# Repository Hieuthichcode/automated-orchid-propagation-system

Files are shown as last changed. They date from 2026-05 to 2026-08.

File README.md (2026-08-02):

# Automated Orchid Propagation System

> A hybrid 2D–3D RGB-D method for estimating the
> growth axis of Phalaenopsis orchid buds and converting the estimated axis into
> a robot-referenced 6-DOF grasp pose, integrated with a custom 6-DOF robot arm.

---

## Demo

<p align="center">
  System Architecture<br/>
  <em>System architecture — Embedded vision computer + 6-DOF robot arm with RGB-D sensing</em>
</p>

<p align="center">
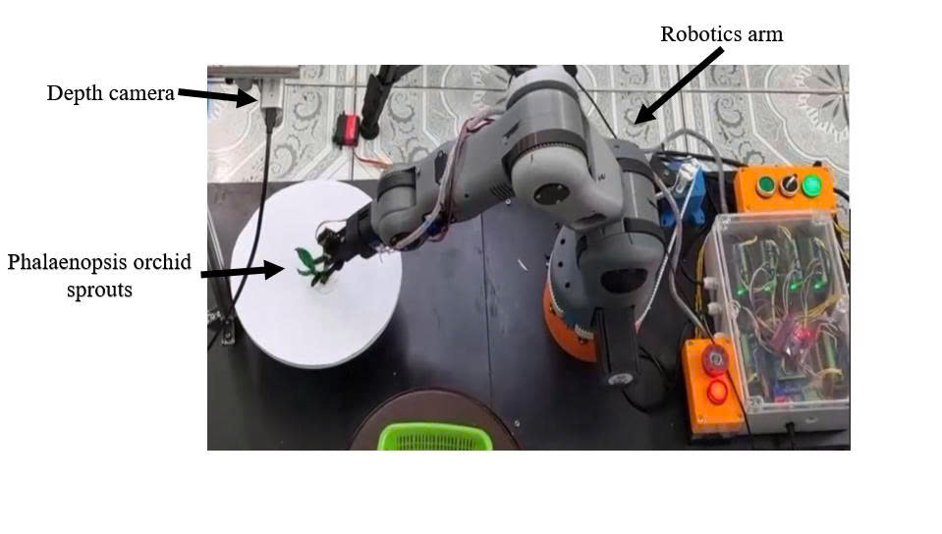
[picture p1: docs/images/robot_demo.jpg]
Robot Demo
  <br/>
  <em>Physical prototype — 6-DOF robot arm performing orchid shoot manipulation</em>
</p>

---

## Overview

This repository implements a hybrid 2D–3D RGB-D method for estimating the
growth axis of Phalaenopsis orchid buds and converting the estimated axis into
a robot-referenced 6-DOF grasp pose. The pipeline combines instance
segmentation, 2D skeleton guidance, depth-based point-cloud processing, and PCA
axis estimation.

This project combines a custom-built **6-DOF serial robot arm** with an **Intel RealSense D435 depth camera** and a **YOLOv8 instance segmentation model** to autonomously detect, locate, and manipulate orchid shoots (*mầm lan*) — replacing manual labor in orchid propagation.

### System Pipeline

```
RGB-D acquisition (RealSense D435)
        │
        ▼
Instance segmentation (YOLOv8, v8_seg_1024.pt)
        │  detect & segment each orchid bud
        ▼
2D skeleton extraction
        │  tip detection, cutting point & angle
        ▼
Point-cloud reconstruction and filtering
        │  depth-based 3D extraction, outlier removal
        ▼
Skeleton-guided branch selection
        │
        ▼
PCA growth-axis estimation
        │
        ▼
Camera-to-robot transformation
        │
        ▼
6-DOF grasp pose → Arduino Mega 2560 (IK on-board)
        │  quintic trajectory interpolation
        ▼
6-DOF Stepper Robot → Cut / Grip / Branch
```

---

## Data and pretrained models

Representative image samples, trained model weights, and the raw numerical
evaluation data are available in the
[Google Drive folder](https://drive.google.com/drive/folders/1FqTuIMWtxHYL037exPB-O3m-0CBoGs5N?usp=drive_link).

The shared folder contains:

- `Images/`: representative JPEG images;
- `Model_train/weights/best.pt`: recommended segmentation weight for inference;
- `Model_train/weights/epoch360.pt` and `last.pt`: additional checkpoints;
- `Data_test/angularError_data.xlsx`: angular-error evaluation data;
- `Data_test/Time_data.xlsx`: processing-time evaluation data.

The dataset consists of Phalaenopsis orchid bud images captured under laboratory
conditions using the Intel RealSense D435 camera, covering diverse lighting,
angles, and growth stages. It contains 3,104 original RGB images split
75%/15%/10% (train/val/test). Following augmentation applied exclusively to the training subset, the complete dataset contained 12,416 images: 11,640 images in the training set, 466 images in the validation set, and 310 images in the test set.

---

## Segmentation model

The instance-segmentation model was trained for 380 epochs using AdamW with a
learning rate of 0.001 and an input size of 1024 × 1024 pixels. The selected
model achieved a mask mAP@0.5 of 0.970 on the validation set.
The repository includes `Vision2D-3D/v8_seg_1024.pt`, which is the
`best.pt` checkpoint from the shared Google Drive folder renamed to match
the filename used by the application. The same checkpoint is also available
as `Model_train/weights/best.pt` in the shared Google Drive folder.

---

## Performance overview

The proposed hybrid method achieved the lowest mean angular error while
remaining substantially faster than the Global 3D PCA baseline.

| Method | Angular error (mean ± SD) | Processing time |
|---|---:|---:|
| 2D Skeleton | 14.2° ± 6.1° | 32 ms |
| Global 3D PCA | 9.3° ± 4.2° | 120 ms |
| Hybrid 2D–3D | 5.1° ± 3.3° | 65 ms |

Results correspond to 520 RGB-D samples from 250 specimens.

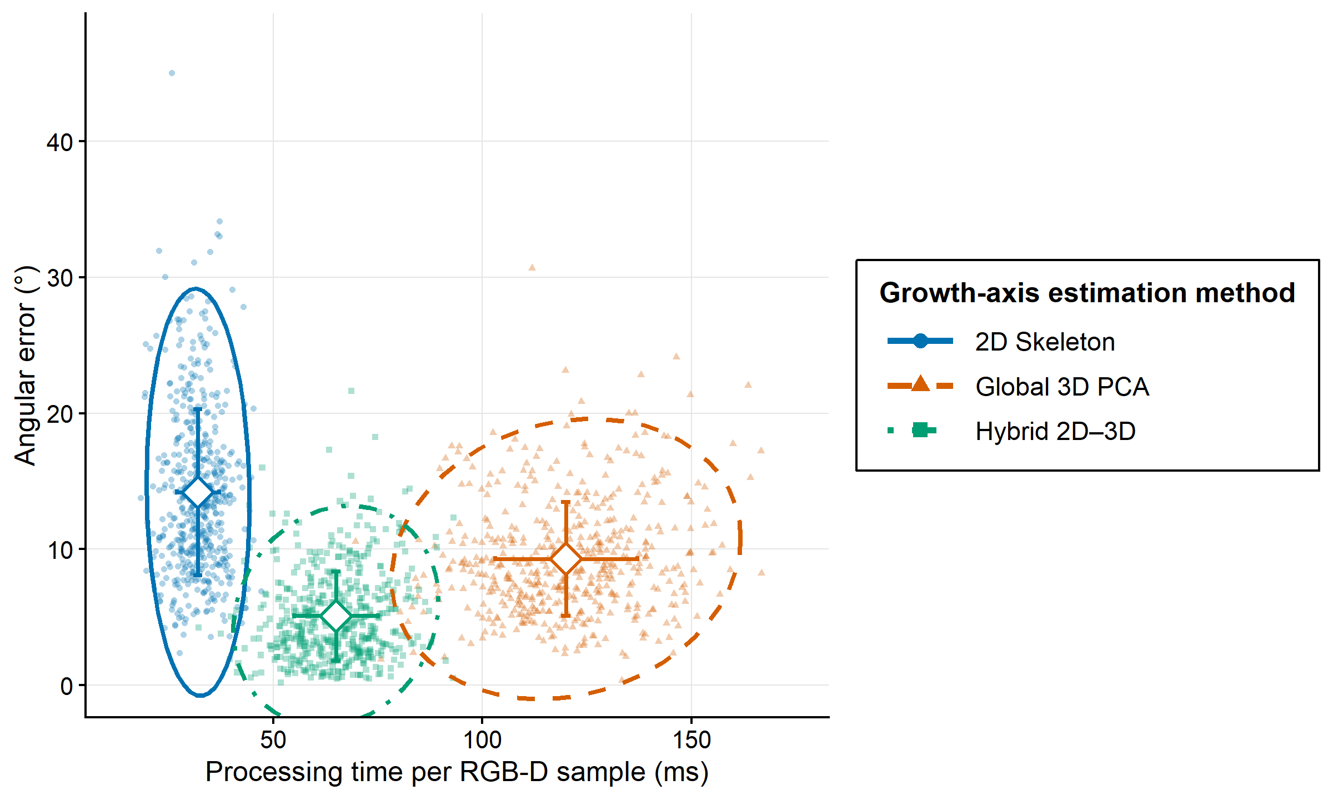
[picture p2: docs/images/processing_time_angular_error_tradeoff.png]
Processing-time and angular-error trade-off


---

## Repository Structure

```
├── CAD/                        # SolidWorks 3D models (.SLDPRT, .SLDASM, .STEP)
│   ├── ROBOT_6DOF_ASSEM.SLDASM   # Full robot assembly
│   ├── ROBOT_6DOF_ASSEM.STEP     # Export for other CAD tools
│   ├── base.SLDPRT, J6.SLDPRT … # Individual part files
│   └── …
│
├── Code_robot_6DOF/
│   └── Code_robot_6DOF.ino     # Arduino Mega 2560 firmware
│
└── Vision2D-3D/
    ├── realsense_gui_advanced.py # Main vision GUI application
    ├── view_pointcloud.py        # Point cloud viewer utility
    ├── v8_seg_1024.pt            # Segmentation model used by the application
    ├── roi_config.txt            # Saved ROI configuration
    ├── Output_image/             # Exported result images
    └── Output_pointcloud/        # Generated automatically at runtime
```

---

## Hardware

| Component | Specification |
|---|---|
| Robot controller | Arduino Mega 2560 |
| Joints | 6× stepper motors (5× TB6600 and 1× TMC2208 drivers) |
| Depth camera | Intel RealSense D435 |
| End-effector | Gripper fabricated from PETG by three-dimensional printing |
| Gripper control | Digital pin D3 (HIGH = close) |
| Task triggers | Digital pins D2, D14, D15 |

### Robot DH Parameters

| Parameter | Value |
|---|---|
| d1 | 231.5 mm |
| a2 | 221.68 mm |
| d3 | 224.75 mm |
| d6 | 202.64 mm |

### Steps Per Revolution (per joint)

| Joint | Steps/Rev |
|---|---|
| J1 | 27 333 |
| J2 | 18 000 |
| J3 | 18 000 |
| J4 | 6 400 |
| J5 | 12 000 |
| J6 | 8 192 |

---

## Software

### 1. Robot Firmware — `Code_robot_6DOF.ino`

- **Inverse Kinematics** computed entirely on-board (no ROS required)
  - Spherical wrist decomposition (analytical IK)
  - DH standard convention (ZYX RPY)
  - Singularity handling + joint limit enforcement
- **Quintic polynomial trajectory** interpolation for smooth motion
- **Coordinated multi-joint motion** — all joints arrive simultaneously
- **Command queue** — up to 100 waypoints (`G` / `GR` commands over Serial)
- **3 motion profiles:** `SMOOTH`, `BALANCED`, `FAST`
- **Speed multiplier** — runtime adjustable (10% – 300%)
- **Hardware task lists** — 3 pre-loadable programs triggered by D2/D14/D15
- **Arc motion** (`GR` command) with configurable steps

#### Serial Command Format

```
G x y z roll pitch yaw [delay] [j6_extra] [d3_state] [gripper_delay]
GR cx cy cz x y z roll pitch yaw [...]   # Arc motion around center
HOME                                      # Return to home position
SPEED <multiplier>                        # e.g. SPEED 1.5
PROFILE <0|1|2>                          # SMOOTH / BALANCED / FAST
STATUS                                    # Print current joint angles
```

---

### 2. Vision Application — `realsense_gui_advanced.py`

**Requirements:** Python 3.11, see [Dependencies](#dependencies)

The application uses the bundled `Vision2D-3D/v8_seg_1024.pt` checkpoint.
The same checkpoint is also available as `Model_train/weights/best.pt` in the
[shared Google Drive folder](https://drive.google.com/drive/folders/1FqTuIMWtxHYL037exPB-O3m-0CBoGs5N?usp=drive_link).

```bash
cd Vision2D-3D
python realsense_gui_advanced.py
```

#### Features

- **Real-time RGB + Depth preview** at 1280×720 @ 30 FPS (cropped to 720×720)
- **YOLOv8s Instance Segmentation** — runs every 5 frames for stability
- **Skeleton analysis** of each segmented shoot:
  - Tip detection (endpoints of skeleton branches)
  - Cutting point & cutting angle calculation
  - 2D (image-plane) or 3D (metric) base coordinate modes
- **3D Point Cloud export** (`.pcd` / `.ply`) with configurable quality
  - Outlier removal, smoothing, bilateral filter
  - Per-instance point cloud or combined
- **JSON tip export** — 3D coordinates + orientation for each instance
- **ROI (Region of Interest)** — draw, save, and auto-load detection area
- **Picking frame visualization** — coordinate axes at stem for robot planning

#### Output Files

| File | Description |
|---|---|
| `Output_pointcloud/*.ply` | Point cloud per instance |
| `Output_pointcloud/*_tips.json` | Tip positions (3D) + cut angle |
| `Output_image/*.png` | Annotated result images |

---

## Dependencies

### Python (Vision)

> **Note:** For CUDA-enabled PyTorch, install it separately using the
> [official PyTorch installation selector](https://pytorch.org/get-started/locally/)
> before running `pip install -r requirements.txt`.

```bash
pip install -r requirements.txt
```

| Package | Verified version |
|---|---|
| pyrealsense2 | 2.55.1.6486 |
| ultralytics (YOLOv8) | 8.3.59 |
| torch | 2.1.2+cu121 |
| torchvision | 0.16.2+cu121 |
| open3d | 0.19.0 |
| opencv-python | 4.10.0.84 |
| numpy | 1.26.4 |
| scipy | 1.13.1 |
| scikit-image | 0.24.0 |

### Arduino

- [AccelStepper](https://www.airspayce.com/mikem/arduino/AccelStepper/) library

---

## Reproducibility

Verified environment for reported results:

```
Python            3.11.9
ultralytics       8.3.59
torch             2.1.2+cu121
torchvision       0.16.2+cu121
opencv-python     4.10.0.84
open3d            0.19.0
numpy             1.26.4
scikit-image      0.24.0
pyrealsense2      2.55.1.6486
scipy             1.13.1
CUDA runtime      12.1
cuDNN             8801
GPU               NVIDIA GeForce RTX 3060
Training seed     0
PyTorch deterministic algorithms: False
```

---

## CAD Models

All mechanical parts are designed in **SolidWorks**. A STEP export (`ROBOT_6DOF_ASSEM.STEP`) is included for compatibility with other CAD tools (Fusion 360, FreeCAD, etc.).

Third-party component models included:
- `stepper 24BYJ-48` — Seeed Studio
- `28BYJ-48` stepper + ULN2003 driver board
- `NEMA17 42-40` stepper
- `Servo SG90` gripper 
- `TB6600` stepper driver
- V-slot rail wheel (625-2Z bearing)

---

## License

This project is developed as a university graduation thesis. Third-party CAD models are subject to their original terms of use (see `CAD/readme-and-terms-of-use-3d-cad-models.txt`).

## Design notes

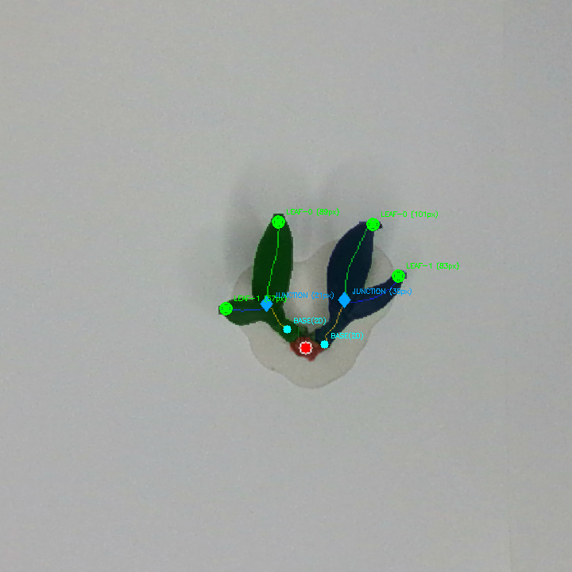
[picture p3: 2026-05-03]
Vision2D-3D/Output_image/preview_20260305_072333.png

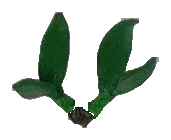
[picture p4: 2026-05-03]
Vision2D-3D/Output_image/mam_clean_20260305_070831.png

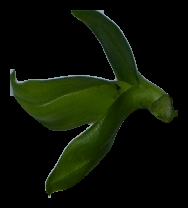
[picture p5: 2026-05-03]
Vision2D-3D/Output_image/instance_1_bud_leaf_conf0.95_20260305_080826.png

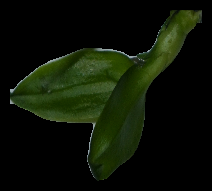
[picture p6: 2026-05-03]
Vision2D-3D/Output_image/instance_2_bud_leaf_conf0.93_20260305_080826.png

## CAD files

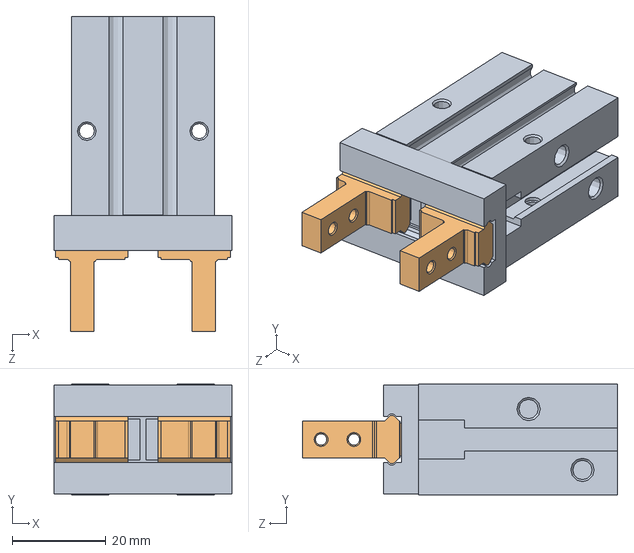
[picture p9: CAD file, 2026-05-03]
CAD/SOLIDWORKS/MHZ2-16D(20_9_0).sldasm
38.0 x 23.6 x 67.3 mm
MHZ2-16D_Body
MHZ2-16D_Finger x 2

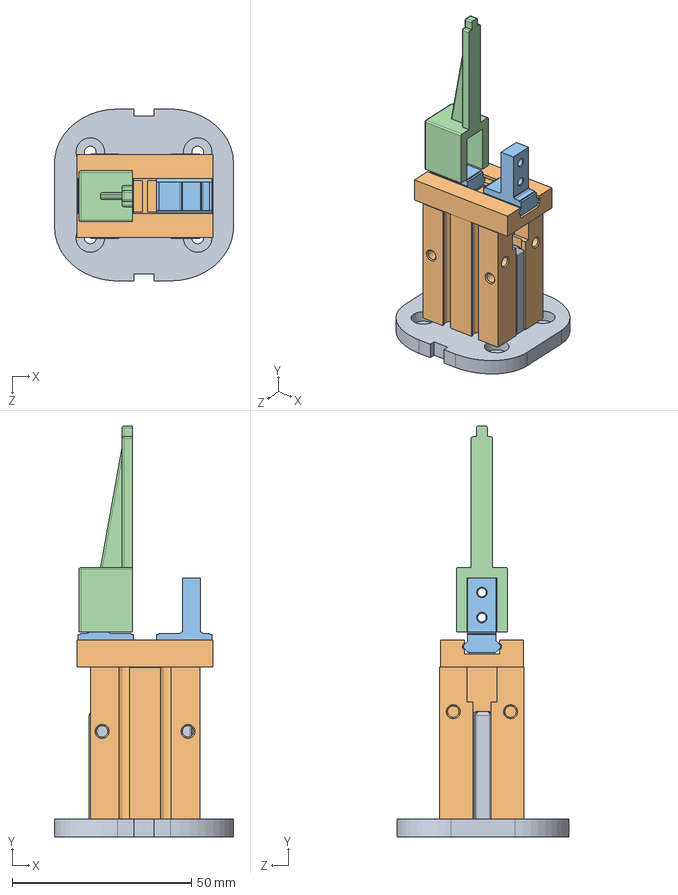
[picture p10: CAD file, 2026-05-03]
CAD/Assem1.SLDASM
50.0 x 114.8 x 48.0 mm
base
MHZ2-16D_Body
MHZ2-16D_Finger x 2
Gripper

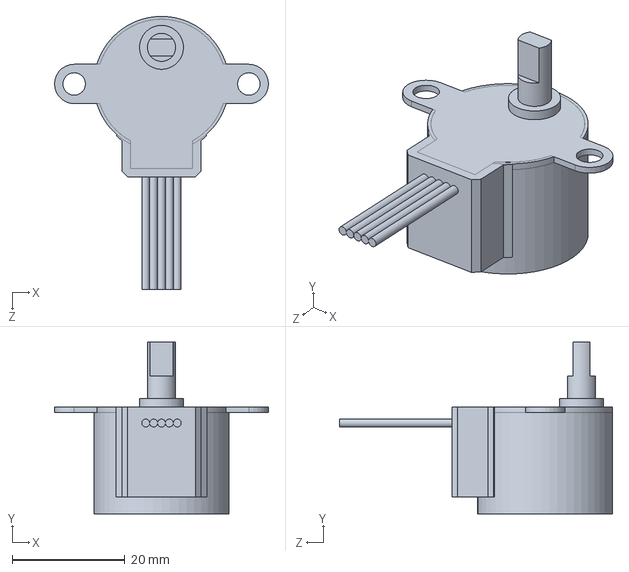
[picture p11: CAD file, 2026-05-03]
CAD/24byj48-seeed-studio-stepper-motor-1.snapshot.5/stepper 24BYJ-48.SLDPRT
38.0 x 30.5 x 48.5 mm

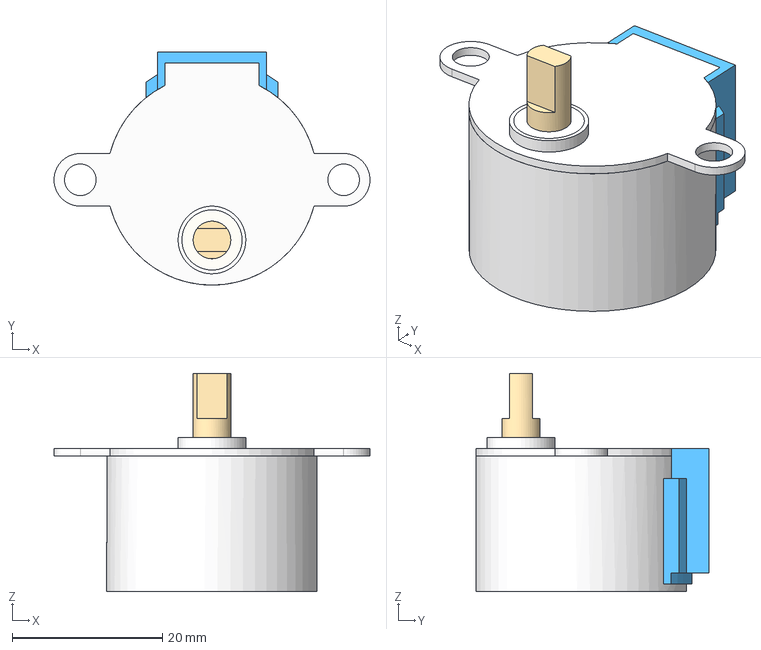
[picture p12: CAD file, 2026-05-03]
CAD/28byj-48-stepper-motor-and-uln2003-stepper-motor-driver-board-1.snapshot.3/28BYJ-48_5VDC.step
42.0 x 31.0 x 29.0 mm

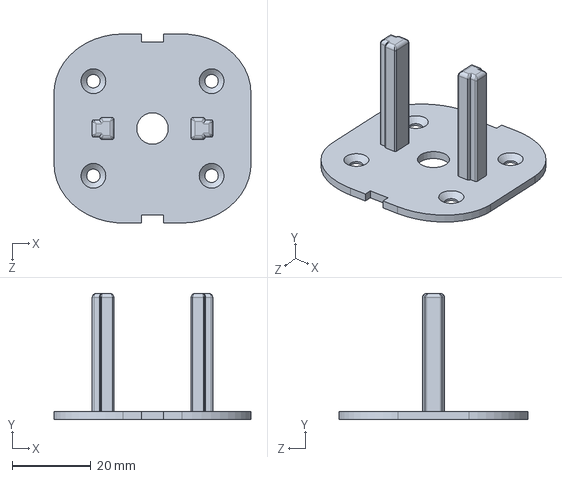
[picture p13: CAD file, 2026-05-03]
CAD/J6_base.SLDPRT
50.0 x 32.0 x 48.0 mm

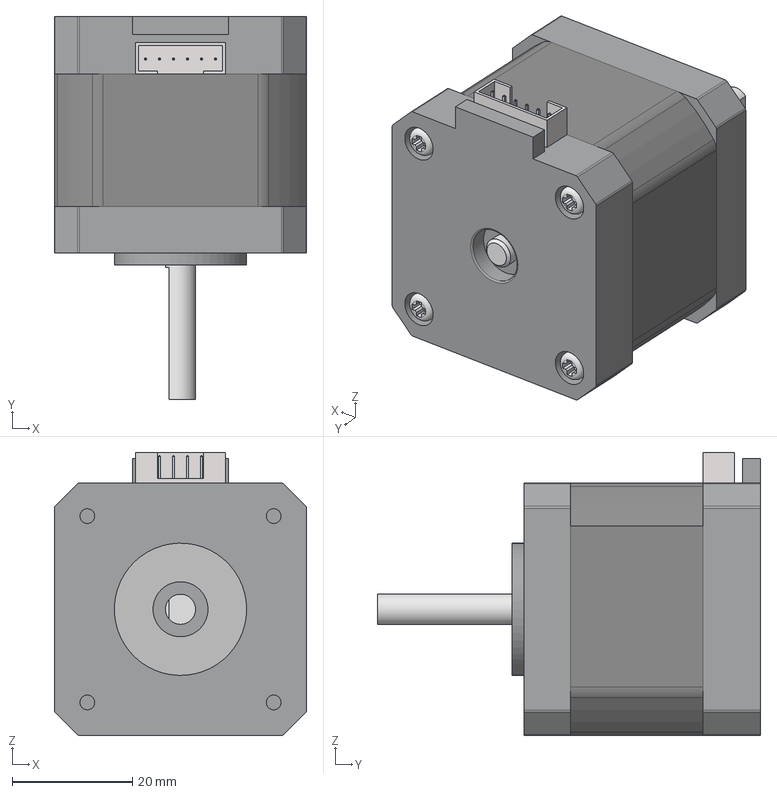
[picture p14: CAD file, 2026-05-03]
CAD/nema17-42-40-1.snapshot.1/NEMA17 42-40.stp
42.0 x 63.8 x 47.1 mm

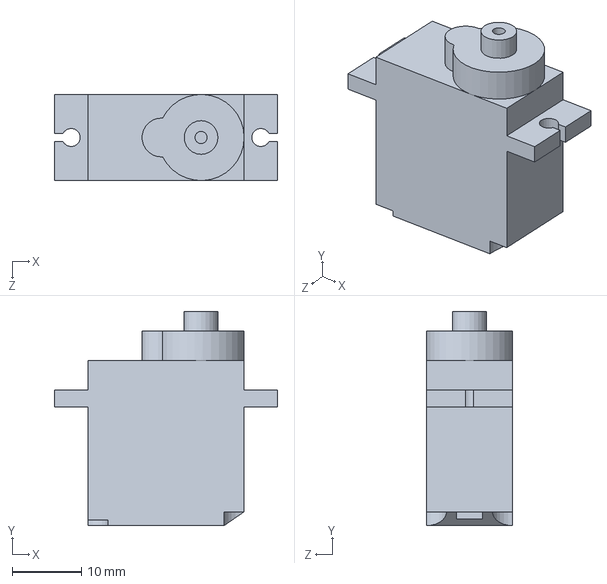
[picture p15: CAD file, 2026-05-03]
CAD/Servo-sg90/Servo SG90.SLDPRT
32.1 x 30.9 x 12.4 mm

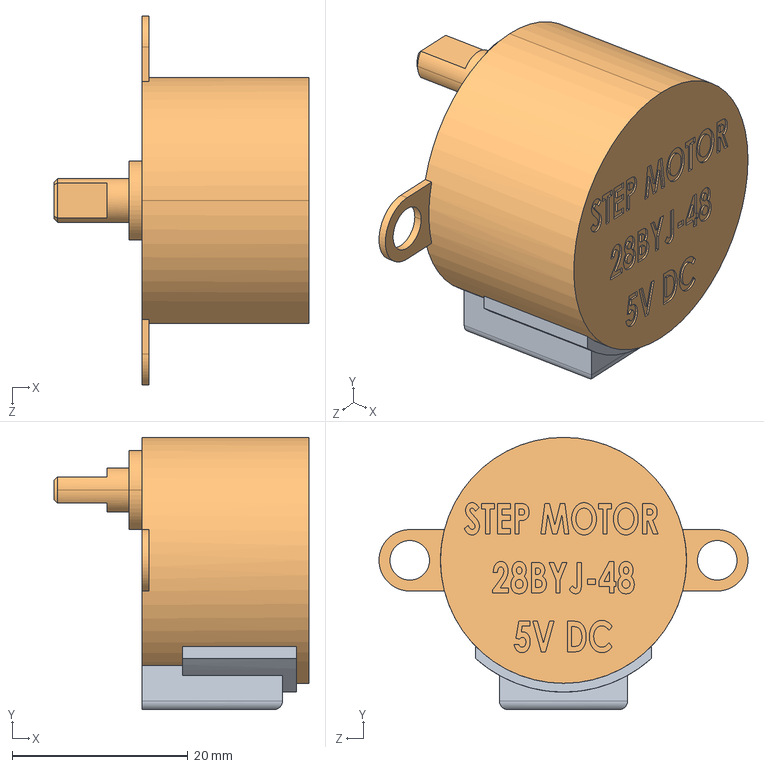
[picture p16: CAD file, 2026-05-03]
CAD/stepper-motor-28byj-48-5v-dc-3.snapshot.4/Stepper motor 28BYJ-48 5V.STEP
29.0 x 31.0 x 42.0 mm

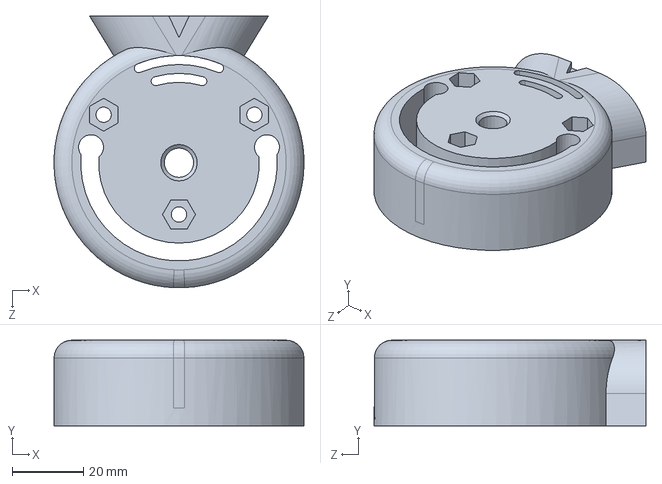
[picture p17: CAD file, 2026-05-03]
CAD/stl/4M2B.SLDPRT
70.0 x 24.0 x 76.0 mm

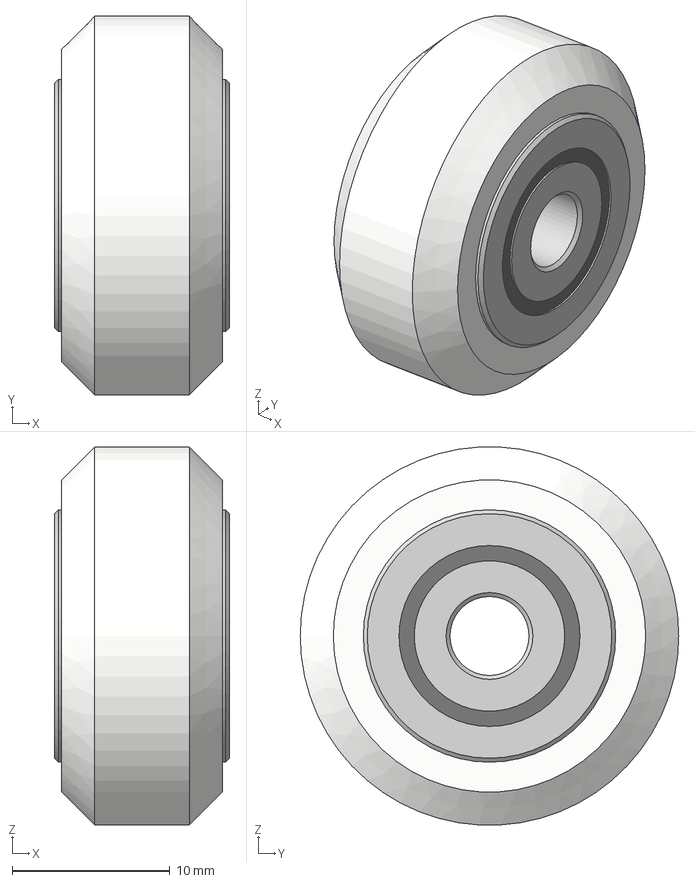
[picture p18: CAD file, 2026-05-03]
CAD/wheel-for-v-slot-rail-system-1.snapshot.1/Wheel, V-slot Rail 625-2Z Bearing v4.step
11.1 x 24.0 x 24.0 mm
6153K690_625-2RS SST BALL BEARING, SEALED v2
6153K690_625-2RS SST BALL BEARING, SEALED v2 (1)
Wheel, V-slot Rail for 625 Bearing
91166A240 WSR, FLAT, M5, STL/Z v1

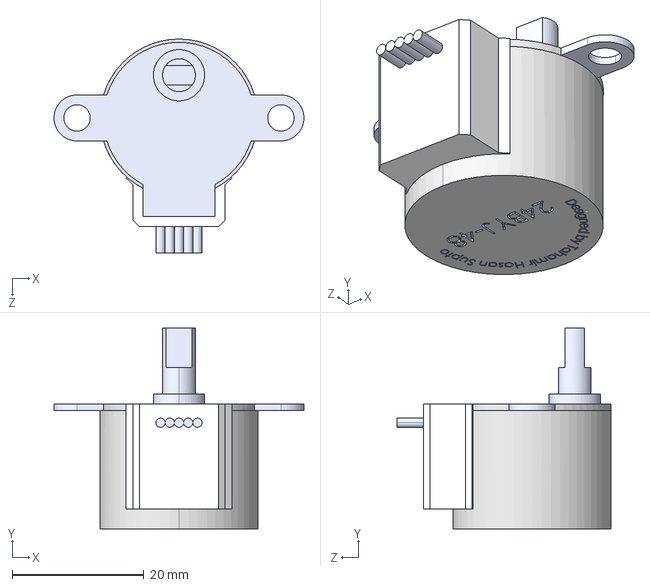
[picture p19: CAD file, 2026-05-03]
CAD/24byj48-seeed-studio-stepper-motor-1.snapshot.5/stepper 24BYJ-48 kew.STEP
38.0 x 30.5 x 32.5 mm

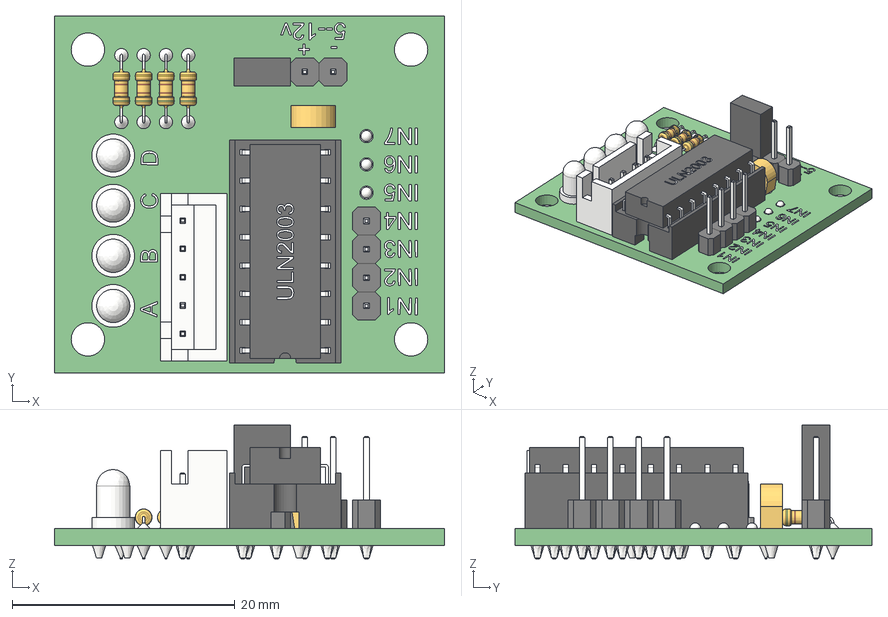
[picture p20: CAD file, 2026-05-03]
CAD/28byj-48-stepper-motor-and-uln2003-stepper-motor-driver-board-1.snapshot.3/ULN2003_Stepper_Motor_Driver_Board.step
35.0 x 32.0 x 12.0 mm
board
5.2Kohm x 4
LED_Small x 4
DIP_16_Socket
ULN2003_DIP-16L
Pin_Header x 8
ceramic_capacitor_104
plug_uln2003
solder x 29
solder2 x 10
solder1 x 8
solder_dot_round x 3
cap

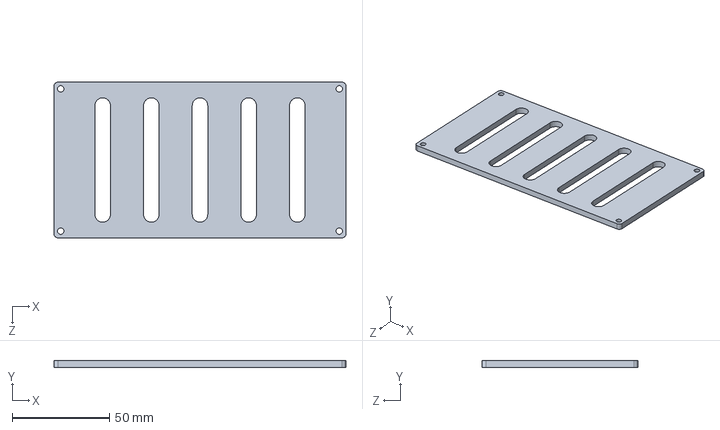
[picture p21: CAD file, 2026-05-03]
CAD/NAP_MEGA2560.SLDPRT
150.0 x 3.50 x 80.0 mm

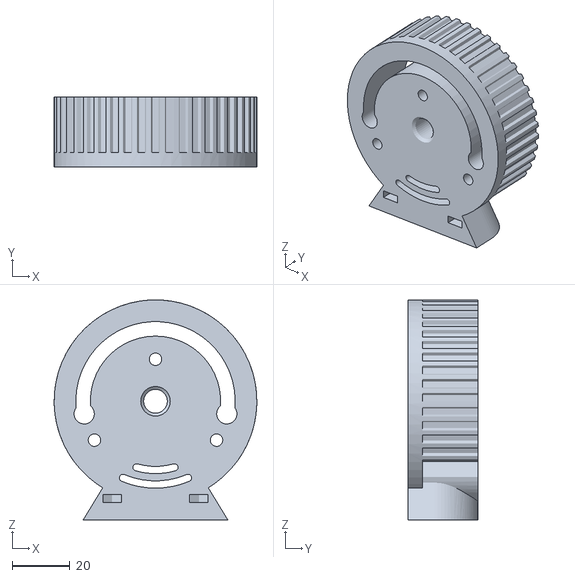
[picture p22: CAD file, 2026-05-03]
CAD/stl/4M2CB.STL
70.0 x 24.0 x 76.0

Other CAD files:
CAD/SMC_JP_MHZ216D2090/SOLIDWORKS/MHZ2-16D(20_9_0).sldasm
CAD/Assem_J6.SLDASM
CAD/SOLIDWORKS/MHZ2-16D_Body.sldprt
CAD/SMC_JP_MHZ216D2090/SOLIDWORKS/MHZ2-16D_Finger.sldprt
CAD/28byj-48-stepper-motor-and-uln2003-stepper-motor-driver-board-1.snapshot.3/28BYJ-48_5VDC.f3d
CAD/28byj-48-stepper-motor-and-uln2003-stepper-motor-driver-board-1.snapshot.3/ULN2003_Stepper_Motor_Driver_Board.f3d
CAD/CANGDAIK1_BASE.SLDPRT
CAD/CANGDAIK1_PART.SLDPRT
CAD/DAO.SLDPRT
CAD/GADAO.SLDPRT
CAD/Gripper.SLDPRT
CAD/HOP_MEGA2560.SLDPRT
CAD/J6.SLDPRT
CAD/J6_2.SLDPRT
CAD/Khớp nối động cơ 5mm.SLDPRT
CAD/Part1 kẹp (1).SLDPRT
CAD/Part1 kẹp (2).SLDPRT
CAD/Part1 kẹp (3).SLDPRT
CAD/Part1 kẹp - Copy.SLDPRT
CAD/Part1 kẹp.SLDPRT
CAD/Part4 (1).SLDPRT
CAD/Part4 hút.SLDPRT
CAD/Part4.SLDPRT
CAD/SMC_JP_MHZ216D2090/SOLIDWORKS/MHZ2-16D_Body.sldprt
CAD/SOLIDWORKS/MHZ2-16D_Finger.sldprt
CAD/base.SLDPRT
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

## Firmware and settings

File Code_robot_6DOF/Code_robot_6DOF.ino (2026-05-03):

/*
 * ROBOT 6DOF - ARDUINO MEGA 2560 - STANDALONE MODE
 * 
 * Chức năng:
 * - Động học ngược (Inverse Kinematics)
 * - Nội suy quỹ đạo quintic mượt
 * - Chạy tự động không cần ROS
 * 
 * Tham số robot (từ MATLAB IK):
 * d1 = 0.2315m, a2 = 0.22168m, d3 = 0.22475m, d6 = 0.20264m
 */

#include <AccelStepper.h>

// ============================================================
// KHAI BÁO CHÂN ĐỘNG CƠ
// ============================================================
#define X_STEP_PIN 54
#define X_DIR_PIN 55
#define X_ENABLE_PIN 38


#define Z_STEP_PIN 46
#define Z_DIR_PIN 48
#define Z_ENABLE_PIN 62

#define Y_STEP_PIN 60
#define Y_DIR_PIN 61
#define Y_ENABLE_PIN 56

#define E0_STEP_PIN 26
#define E0_DIR_PIN 28
#define E0_ENABLE_PIN 24

#define E1_STEP_PIN 36
#define E1_DIR_PIN 34
#define E1_ENABLE_PIN 30

#define E2_STEP_PIN 47
#define E2_DIR_PIN 45
#define E2_ENABLE_PIN 32

#define GRIPPER_PIN 3  // Chân D3 điều khiển gripper (1=HIGH đóng, 0=LOW mở)

// ============================================================
// TẠO STEPPER
// ============================================================
AccelStepper joint1(AccelStepper::DRIVER, X_STEP_PIN, X_DIR_PIN);
AccelStepper joint2(AccelStepper::DRIVER, Z_STEP_PIN, Z_DIR_PIN);
AccelStepper joint3(AccelStepper::DRIVER, Y_STEP_PIN, Y_DIR_PIN);
AccelStepper joint4(AccelStepper::DRIVER, E0_STEP_PIN, E0_DIR_PIN);
AccelStepper joint5(AccelStepper::DRIVER, E1_STEP_PIN, E1_DIR_PIN);
AccelStepper joint6(AccelStepper::DRIVER, E2_STEP_PIN, E2_DIR_PIN);
AccelStepper* const JOINTS[6] = {&joint1, &joint2, &joint3, &joint4, &joint5, &joint6};

// ============================================================
// THÔNG SỐ ROBOT
// ============================================================
const float d1 = 0.2315;   // m
const float a2 = 0.22168;  // m
const float d3 = 0.22475;  // m
const float d6 = 0.20264;  // m

// Steps per revolution cho mỗi khớp
const long STEPS_PER_REV[6] = {27333, 18000, 18000, 6400, 12000, 8192};
// Home position offset (rad) - Robot's physical home position
// J4: offset = 0 vì bù -180° được trừ TRỰC TIẾP vào q_rad[3] sau khi IK, trước khi tính xung
// J5: offset = 0 vì bù -90° được trừ TRỰC TIẾP vào q_rad[4] sau khi IK, trước khi tính xung
const float HOME_OFFSET[6] = {0.0, PI/2, 0.0, 0.0, 0.0, -PI};

// Góc DH của các khớp tại vị trí HOME vật lý (tất cả motor ở step 0)
// J1=0, J2=PI/2 (tay thẳng đứng), J3=0
// J4=PI  (do loop trừ PI trước rad_to_steps)
// J5=PI/2 (do loop trừ PI/2 trước rad_to_steps)
// J6=-PI (HOME_OFFSET[5]=-PI)
const float HOME_Q_IK[6] = {0.0, PI/2, 0.0, PI, PI/2, -PI};

// Giới hạn góc (rad) - ĐO TƯƠNG ĐỐI SO VỚI HOME_Q_IK (khung motor)
// Ví dụ: Q_MAX[1]=PI/2 nghĩa là J2 được đi ±PI/2 từ vị trí home
const float Q_MIN[6] = {-PI, -PI/2, -2*PI/3, -PI, -5*PI/9, -PI};
const float Q_MAX[6] = {PI, PI/2, 2*PI/3, PI, 5*PI/9, PI};

// Góc khớp trước đó (để unwrap liên tục)
// Khởi tạo = HOME_Q_IK (robot bắt đầu ở home)
float q_prev[6] = {0.0, PI/2, 0.0, PI, PI/2, -PI};

// Góc IK nghiệm cuối cùng thành công (frame DH, trước bù J4/J5).
// Đây là tham chiếu THỰC TẾ để unwrap_angle tìm nghiệm gần vị trí hiện tại nhất.
// Khởi tạo = HOME_Q_IK
float q_current_ik[6] = {0.0, PI/2, 0.0, PI, PI/2, -PI};

// ============================================================
// CHẾ ĐỘ ĐIỀU KHIỂN
// ============================================================
enum ControlMode {
  MODE_QUEUE,   // Run queued G/GR commands
  MODE_MANUAL,  // Manual single target
  MODE_IDLE     // Stop
};

ControlMode control_mode = MODE_IDLE;

// Target position for manual mode
float target_p[3] = {0, 0, 0.855};
float target_rpy[3] = {0, 0, 0};
bool has_new_target = false;

// Queue of targets from G/GR commands
#define MAX_QUEUE 100
#define TASK_LIST_COUNT 3
#define MAX_TASK_ITEMS 20
#define ARC_STEPS 35
float queue_p[MAX_QUEUE][3];
float queue_rpy[MAX_QUEUE][3];
float queue_delay_s[MAX_QUEUE];
float queue_j6_extra[MAX_QUEUE]; // Extra rotation for Joint 6 (in radians)
bool queue_auto_orient[MAX_QUEUE]; // True if IK0 mode (auto find orientation)
int8_t queue_d3_state[MAX_QUEUE]; // Trạng thái chân D3: 1=HIGH, 0=LOW, -1=không thay đổi
float queue_gripper_delay_s[MAX_QUEUE]; // Thời gian chờ trước khi kích gripper (giây)
int queue_count = 0;
int queue_index = 0;
bool queue_running = false;
bool queue_step_active = false;
float last_g_center[3] = {0.0f, 0.0f, 0.0f};
bool last_g_center_valid = false;

const uint8_t TASK_TRIGGER_PINS[TASK_LIST_COUNT] = {2, 14, 15};
const char* const TASK_TRIGGER_NAMES[TASK_LIST_COUNT] = {"D2", "D14", "D15"};
const unsigned long TASK_TRIGGER_DEBOUNCE_MS = 40;
int16_t task_p_mm[TASK_LIST_COUNT][MAX_TASK_ITEMS][3];
int16_t task_rpy_deg10[TASK_LIST_COUNT][MAX_TASK_ITEMS][3];
uint16_t task_delay_cs[TASK_LIST_COUNT][MAX_TASK_ITEMS];
int16_t task_j6_extra_deg10[TASK_LIST_COUNT][MAX_TASK_ITEMS];
int8_t task_d3_state[TASK_LIST_COUNT][MAX_TASK_ITEMS];
uint16_t task_gripper_delay_cs[TASK_LIST_COUNT][MAX_TASK_ITEMS];
uint8_t task_count[TASK_LIST_COUNT] = {0, 0, 0};
bool task_trigger_prev_state[TASK_LIST_COUNT] = {false, false, false};
bool task_trigger_raw_state[TASK_LIST_COUNT] = {false, false, false};
bool task_trigger_latched[TASK_LIST_COUNT] = {false, false, false};
unsigned long task_trigger_last_change_ms[TASK_LIST_COUNT] = {0, 0, 0};

// Biến cho non-blocking movement
bool is_moving = false;
unsigned long move_delay_start = 0;
bool waiting_for_delay = false;
bool waiting_for_gripper = false;    // Đang chờ trước khi kích gripper
unsigned long gripper_delay_start = 0;

// Speed control (percentage: 50% = 0.5, 100% = 1.0, 200% = 2.0)
float speed_multiplier = 1.0;
const float SPEED_MIN = 0.1;  // 10% minimum
const float SPEED_MAX = 3.0;  // 300% maximum
// Nang tran toc do toan bo cac khop de test xem rung/on co den tu co khi hay khong.
const float BASE_MAX_SPEEDS[6] = {1550.0, 850.0, 3200.0, 650.0, 1200.0, 700.0};
const float BASE_MAX_ACCELS[6] = {1000.0, 2000.0, 3500.0, 1000.0, 1000.0, 1000.0};
const float COORD_MIN_SPEEDS[6] = {180.0, 120.0, 200.0, 100.0, 140.0, 100.0};
const float COORD_MIN_ACCELS[6] = {90.0, 60.0, 110.0, 40.0, 80.0, 50.0};
const unsigned int MIN_STEP_PULSE_US = 8;
const long SHORT_MOVE_THRESHOLD_STEPS = 900;
const float SHORT_MOVE_SPEED_SCALE_MIN = 0.42f;
const float SHORT_MOVE_ACCEL_SCALE_MIN = 0.25f;
const float SHORT_MOVE_FLOOR_SCALE_MIN = 0.50f;

// Gearbox tuning rieng cho J3: tang toc/ham nhanh hon de thoat som vung cong huong,
// nhung van giu 1 muc giam nhe khi doi chieu de tranh dap backlash cua hop so.
const float JOINT_SPEED_SCALES[6] = {1.00, 1.00, 0.85, 1.00, 1.00, 1.00};
const float JOINT_ACCEL_SCALES[6] = {1.00, 1.00, 0.55, 1.00, 1.00, 1.00};
const float JOINT_MIN_SPEED_SCALES[6] = {1.00, 1.00, 1.25, 1.00, 1.00, 1.00};
const float JOINT_MIN_ACCEL_SCALES[6] = {1.00, 1.00, 1.00, 1.00, 1.00, 1.00};
const float J3_REVERSE_SPEED_SCALE = 1.92;
const float J3_REVERSE_ACCEL_SCALE = 1.75;

// Doi 1 bien nay de debug profile chuyen dong.
enum MotionProfileMode {
  PROFILE_SMOOTH = 0,
  PROFILE_BALANCED = 1,
  PROFILE_FAST = 2
};

struct MotionProfile {
  const char* name;
  float speed_scale;
  float accel_scale;
};

uint8_t motion_profile_mode = PROFILE_BALANCED;

const MotionProfile MOTION_PROFILES[] = {
  {"SMOOTH",   1.5, 1.20},
  {"BALANCED", 1.6, 1.30},
  {"FAST",     1.5, 1.4}
};

long active_move_targets[6] = {0, 0, 0, 0, 0, 0};
long active_move_delta[6] = {0, 0, 0, 0, 0, 0};
long previous_move_delta[6] = {0, 0, 0, 0, 0, 0};
float active_move_speeds[6] = {0, 0, 0, 0, 0, 0};
float active_move_accels[6] = {0, 0, 0, 0, 0, 0};
long active_lead_distance = 0;
bool coordinated_plan_active = false;

const MotionProfile& currentMotionProfile();
void updateMotorSpeeds();
void clearCoordinatedMotionPlan();
void refreshActiveMoveSpeeds();
void beginCoordinatedMove(const long* targetSteps);
bool enqueueTaskCommand(int task_idx,
                        float x, float y, float z,
                        float r, float p, float yaw,
                        float delay_s, float j6_extra_deg,
                        int8_t d3_state, float gripper_delay_s);
bool startTaskList(int task_idx, const char* source_name, bool quiet_failures);
void clearTaskList(int task_idx);
void printTaskList(int task_idx);
void checkTaskTriggerInputs();

// ============================================================
// WAYPOINTS (từ MATLAB)
// ============================================================
const int NUM_WAYPOINTS = 4;
float P_waypoints[4][3] = {
  {0.0,  0.00,  0.88057},  // P0
  {0.4,  0.30,  0.2315},    // P1
  {0.2,  0.10,  0.60},    // P2
  {0.4,  0.10,  0.60}     // P3
};

float R_waypoints[4][3] = {
  {0.0,   0.0,     0.0},    // R0 [roll, pitch, yaw]
  {0.0,   1.5708,  0.0},    // R1
  {0.0,   1.5708,  0.0},    // R2
  {0.0,   1.5708,  0.0}     // R3
};

// RPY unwrapped (tính một lần trong setup)
float Ru_waypoints[4][3];

const float T_TOTAL = 35; // giây
const int NUM_SEGMENTS = 3;
const float T_SEG = T_TOTAL / NUM_SEGMENTS;

// ============================================================
// CẤU TRÚC DỮ LIỆU
// ============================================================
struct Vec3 {
  float x, y, z;
};

struct Mat3 {
  float m[3][3];
};

struct DH_Transform {
  float m[4][4];
};

// ============================================================
// HÀM TOÁN HỌC CƠ BẢN
// ============================================================

// Unwrap góc về gần ref nhất
float unwrap_angle(float angle, float ref) {
  float da = angle - ref;
  da = fmod(da + PI, 2*PI) - PI;
  return ref + da;
}

// Unwrap vector 3D
void unwrap_vec3(float* result, const float* vec, const float* ref) {
  for (int i = 0; i < 3; i++) {
    result[i] = unwrap_angle(vec[i], ref[i]);
  }
}

// RPY (ZYX) to Rotation Matrix
void rpy2rotm_ZYX(Mat3* R, float roll, float pitch, float yaw) {
  float cr = cos(roll),  sr = sin(roll);
  float cp = cos(pitch), sp = sin(pitch);
  float cy = cos(yaw),   sy = sin(yaw);
  
  R->m[0][0] = cy*cp;
  R->m[0][1] = cy*sp*sr - sy*cr;
  R->m[0][2] = cy*sp*cr + sy*sr;
  
  R->m[1][0] = sy*cp;
  R->m[1][1] = sy*sp*sr + cy*cr;
  R->m[1][2] = sy*sp*cr - cy*sr;
  
  R->m[2][0] = -sp;
  R->m[2][1] = cp*sr;
  R->m[2][2] = cp*cr;
}

// Standard DH transform
void dh_std(DH_Transform* T, float a, float alpha, float d, float theta) {
  float ct = cos(theta), st = sin(theta);
  float ca = cos(alpha), sa = sin(alpha);
  
  T->m[0][0] = ct;      T->m[0][1] = -st*ca;   T->m[0][2] = st*sa;    T->m[0][3] = a*ct;
  T->m[1][0] = st;      T->m[1][1] = ct*ca;    T->m[1][2] = -ct*sa;   T->m[1][3] = a*st;
  T->m[2][0] = 0;       T->m[2][1] = sa;       T->m[2][2] = ca;       T->m[2][3] = d;
  T->m[3][0] = 0;       T->m[3][1] = 0;        T->m[3][2] = 0;        T->m[3][3] = 1;
}

// Nhân 2 ma trận 4x4
void mat4_mult(DH_Transform* result, const DH_Transform* A, const DH_Transform* B) {
  for (int i = 0; i < 4; i++) {
    for (int j = 0; j < 4; j++) {
      result->m[i][j] = 0;
      for (int k = 0; k < 4; k++) {
        result->m[i][j] += A->m[i][k] * B->m[k][j];
      }
    }
  }
}

// Nhân 2 ma trận 3x3
void mat3_mult(Mat3* result, const Mat3* A, const Mat3* B) {
  for (int i = 0; i < 3; i++) {
    for (int j = 0; j < 3; j++) {
      result->m[i][j] = 0;
      for (int k = 0; k < 3; k++) {
        result->m[i][j] += A->m[i][k] * B->m[k][j];
      }
    }
  }
}

// Chuyển vị ma trận 3x3
void mat3_transpose(Mat3* result, const Mat3* A) {
  for (int i = 0; i < 3; i++) {
    for (int j = 0; j < 3; j++) {
      result->m[i][j] = A->m[j][i];
    }
  }
}

// ============================================================
// WRIST IK (Spherical wrist)
// ============================================================
bool wrist_from_R36(const Mat3* R36, float* q4, float* q5, float* q6) {
  float s5 = sqrt(R36->m[0][2]*R36->m[0][2] + R36->m[1][2]*R36->m[1][2]);
  float c5 = R36->m[2][2];
  *q5 = atan2(s5, c5);
  
  if (s5 < 1e-6) {
    // Singularity
    *q4 = 0;
    *q6 = atan2(R36->m[1][0], R36->m[0][0]);
    return true;
  }
  
  *q4 = atan2(R36->m[1][2], R36->m[0][2]);
  *q6 = atan2(-R36->m[2][1], R36->m[2][0]);
  return true;
}

// Mức IK đã dùng (1=J1235, 2=J12345, 3=J123456)
int g_ik_level = 3;
float g_ik_motion_cost = 1e30f;

// Ngưỡng sai số FK để chấp nhận nghiệm rút gọn
const float IK_POS_TOL = 0.001f;   // 1 mm
const float IK_ROT_TOL = 0.15f;    // ~6° (Frobenius norm)
const float IK_COST_TIE_EPS = 1e-5f;

// ============================================================
// KIỂM TRA WRIST BẰNG CÔNG THỨC PHÂN TÍCH (không cần full FK)
// → nhanh hơn ~10× so với forward_kinematics_rot trong vòng lặp IK
// ============================================================
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
void loop() {
  // Kiểm tra lệnh Serial
  parseSerialCommand();
  checkTaskTriggerInputs();
  
  float p06[3], rpy[3];
  bool should_move = false;

  // Nếu đang di chuyển, tiếp tục chạy các motor (non-blocking)
  if (is_moving) {
    // Kiểm tra xem có lệnh STOP hoặc lệnh khác không
    if (control_mode == MODE_IDLE && !queue_running) {
      // Người dùng đã nhấn S hoặc lệnh khác làm dừng queue
      digitalWrite(13, LOW);
      is_moving = false;
      clearCoordinatedMotionPlan();
      Serial.println(F("Movement stopped by user"));
      return;
    }
    
    // Planner phoi hop cac khop voi run() rieng cho tung motor
    for (int i = 0; i < 6; i++) {
      JOINTS[i]->run();
    }
    
    // Kiểm tra xem tất cả motor đã đến vị trí chưa
    bool all_done = true;
    for (int i = 0; i < 6; i++) {
      if (JOINTS[i]->distanceToGo() != 0) {
        all_done = false;
        break;
      }
    }
    
    if (all_done) {
      // Tất cả motor đã đến vị trí
      digitalWrite(13, LOW);
      is_moving = false;
      clearCoordinatedMotionPlan();

      if (control_mode == MODE_QUEUE && queue_step_active) {
        Serial.print(F("Position reached! Queue index "));
        Serial.println(queue_index);

        // Kích chân D3 theo tham số gripper của điểm này
        int8_t d3 = queue_d3_state[queue_index];
        float gdelay = queue_gripper_delay_s[queue_index];

        if (d3 != -1) {
          if (gdelay > 0.0f) {
            // Chờ gripper_delay_s rồi mới kích D3 (non-blocking)
            waiting_for_gripper = true;
            gripper_delay_start = millis();
            Serial.print(F("[GRIPPER] Se kich D3 sau "));
            Serial.print(gdelay, 1);
            Serial.println(F("s..."));
          } else {
            // Kích D3 ngay lập tức
            if (d3 == 1) {
              digitalWrite(GRIPPER_PIN, HIGH);
              Serial.println(F("Gripper D3 -> HIGH (dong)"));
            } else {
              digitalWrite(GRIPPER_PIN, LOW);
              Serial.println(F("Gripper D3 -> LOW (mo)"));
            }
          }
        }

        // Kiểm tra delay (chỉ xử lý nếu không đang chờ gripper)
        if (!waiting_for_gripper) {
          if (queue_delay_s[queue_index] > 0.0f) {
            waiting_for_delay = true;
            move_delay_start = millis();
          } else {
            queue_index++;
            queue_step_active = false;
            if (queue_index >= queue_count) {
              control_mode = MODE_IDLE;
              queue_running = false;
              Serial.println(F("QUEUE COMPLETED"));
            }
          }
        }
      }
      
      if (control_mode == MODE_MANUAL) {
        Serial.println(F("Position reached!"));
        Serial.println();
        control_mode = MODE_IDLE; // Chuyển về IDLE để sẵn sàng nhận lệnh mới
      }
    }
    return; // Quay lại đầu loop để có thể nhận lệnh mới
  }
  
  // Kiểm tra chờ gripper delay (trước khi kích D3)
  if (waiting_for_gripper) {
    if (control_mode != MODE_QUEUE) {
      waiting_for_gripper = false;
    } else {
      unsigned long elapsed = millis() - gripper_delay_start;
      float gdelay = queue_gripper_delay_s[queue_index];
      static unsigned long last_debug_ms = 0;
      if (millis() - last_debug_ms >= 500) {
        last_debug_ms = millis();
        Serial.print(F("[GRIPPER] cho: "));
        Serial.print(elapsed / 1000.0f, 1);
        Serial.print(F("s / "));
        Serial.print(gdelay, 1);
        Serial.println(F("s"));
      }
      if (elapsed >= (unsigned long)(gdelay * 1000.0f)) {
        waiting_for_gripper = false;
        // Kích D3 sau khi hết thời gian chờ
        int8_t d3 = queue_d3_state[queue_index];
        if (d3 == 1) {
          digitalWrite(GRIPPER_PIN, HIGH);
          Serial.println(F("Gripper D3 -> HIGH (dong)"));
        } else if (d3 == 0) {
          digitalWrite(GRIPPER_PIN, LOW);
          Serial.println(F("Gripper D3 -> LOW (mo)"));
        }
        // Sau khi kích gripper, xử lý delay_s như bình thường
        if (queue_delay_s[queue_index] > 0.0f) {
          waiting_for_delay = true;
          move_delay_start = millis();
        } else {
          queue_index++;
          queue_step_active = false;
          if (queue_index >= queue_count) {
            control_mode = MODE_IDLE;
            queue_running = false;
            Serial.println(F("QUEUE COMPLETED"));
          }
        }
      }
      return;
    }
  }

  // Kiểm tra delay giữa các bước trong queue
  if (waiting_for_delay) {
    // Kiểm tra xem có lệnh mới làm thay đổi control_mode không
    if (control_mode != MODE_QUEUE) {
      // Người dùng đã gửi lệnh mới (H, S, v.v.), hủy delay
      waiting_for_delay = false;
      waiting_for_gripper = false;
      queue_running = false;
      queue_step_active = false;
      Serial.println(F("Delay interrupted by new command"));
      // Không return, để xử lý lệnh mới bên dưới
    } else {
      unsigned long elapsed = millis() - move_delay_start;
      if (elapsed >= (unsigned long)(queue_delay_s[queue_index] * 1000.0f)) {
        waiting_for_delay = false;
        queue_index++;
        queue_step_active = false;
        if (queue_index >= queue_count) {
          control_mode = MODE_IDLE;
          queue_running = false;
          Serial.println(F("QUEUE COMPLETED"));
        }
      }
      return; // Tiếp tục chờ delay
    }
  }
  
  // Xử lý theo mode
  if (control_mode == MODE_QUEUE) {
    if (!queue_running) {
      queue_running = true;
      queue_step_active = false;
    }

    if (queue_index >= queue_count) {
      control_mode = MODE_IDLE;
      queue_running = false;
      Serial.println(F("QUEUE COMPLETED"));
      delay(100);
      return;
    }

    if (!queue_step_active) {
      p06[0] = queue_p[queue_index][0];
      p06[1] = queue_p[queue_index][1];
      p06[2] = queue_p[queue_index][2];
      rpy[0] = queue_rpy[queue_index][0];
      rpy[1] = queue_rpy[queue_index][1];
      rpy[2] = queue_rpy[queue_index][2];
      should_move = true;
      queue_step_active = true;
    }
  }
  else if (control_mode == MODE_MANUAL && has_new_target) {
    // MANUAL MODE: Di chuyển đến target
    p06[0] = target_p[0];
    p06[1] = target_p[1];
    p06[2] = target_p[2];
    rpy[0] = target_rpy[0];
    rpy[1] = target_rpy[1];
    rpy[2] = target_rpy[2];
    should_move = true;
    has_new_target = false;
  }
  else if (control_mode == MODE_IDLE) {
    // IDLE MODE: Không làm gì, chỉ chờ lệnh mới
    // Không return ngay, vì có thể có should_move từ lệnh vừa nhận
  }
  
  // Thực hiện IK và di chuyển
  if (should_move) {
    float q_rad[6];
    bool valid = false;
    
    // Kiểm tra xem có phải chế độ auto orient không
    bool use_auto_orient = false;
    if (control_mode == MODE_QUEUE && queue_step_active) {
      use_auto_orient = queue_auto_orient[queue_index];
    }
    
    if (use_auto_orient) {
      // Chế độ IK0: Tự động tìm hướng hợp lệ
      float found_rpy[3];
      valid = ik6dof_auto_orient(p06[0], p06[1], p06[2], q_rad, found_rpy);
      
      if (valid) {
        Serial.print(F("  Auto-found orientation: RPY=("));
        Serial.print(found_rpy[0]*180/PI, 2); Serial.print(F(" deg,"));
        Serial.print(found_rpy[1]*180/PI, 2); Serial.print(F(" deg,"));
        Serial.print(found_rpy[2]*180/PI, 2); Serial.println(F(" deg)"));
        
        // Cập nhật RPY cho điểm này
        rpy[0] = found_rpy[0];
        rpy[1] = found_rpy[1];
        rpy[2] = found_rpy[2];
      }
    } else {
      // Chế độ thông thường: Dùng hướng đã cho
      valid = ik6dof_from_p06_rpy(p06[0], p06[1], p06[2], 
                                   rpy[0], rpy[1], rpy[2], 
                                   q_rad);
    }
    
    // Apply J6 extra rotation if in queue mode
    if (valid && control_mode == MODE_QUEUE && queue_step_active) {
      float j6_extra = queue_j6_extra[queue_index];
      if (j6_extra != 0) {
        float before = q_rad[5] * 180 / PI;
        q_rad[5] += j6_extra; // Add extra rotation to Joint 6
        float after = q_rad[5] * 180 / PI;
        Serial.print(F("J6: "));
        Serial.print(before, 1);
        Serial.print(F(" deg -> "));
        Serial.print(after, 1);
        Serial.print(F(" deg (+"));
        Serial.print(j6_extra * 180 / PI, 1);
        Serial.println(F(" deg)"));
      }
    }
    
    if (valid) {
      // In mức IK đã dùng
      switch (g_ik_level) {
        case 1:
          Serial.println(F("[IK] Level 1: J1,J2,J3,J5 du 6DOF - J4=0, J6=0"));
          break;
        case 2:
          Serial.println(F("[IK] Level 2: J1,J2,J3,J4,J5 du 6DOF - J6=0"));
          break;
        default:
          Serial.println(F("[IK] Level 3: Day du 6 khop"));
          break;
      }
    }
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
